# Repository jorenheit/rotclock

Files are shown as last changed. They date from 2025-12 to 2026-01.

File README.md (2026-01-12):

# Roatating Clock Device

This project rotates an entire analog wall clock so that **one selected hand remains stationary with respect to the room**.

The clock itself is a standard off-the-shelf wall clock. It is mounted inside a rigid outer ring with gear teeth. By rotating this ring at a carefully controlled speed (using a stepper motor and reduction gearing), the apparent motion of the second, minute, or hour hand can be canceled. An internal clock, based on the Arduino core function `millis()` is used to determine the frequency of the stepper motors, which is periodically synchronized with a real-time clock (DS3231) to make sure that the system keeps time correctly over longer periods of time, since `millis()` will tend to drift by multiple seconds per day on its own. 

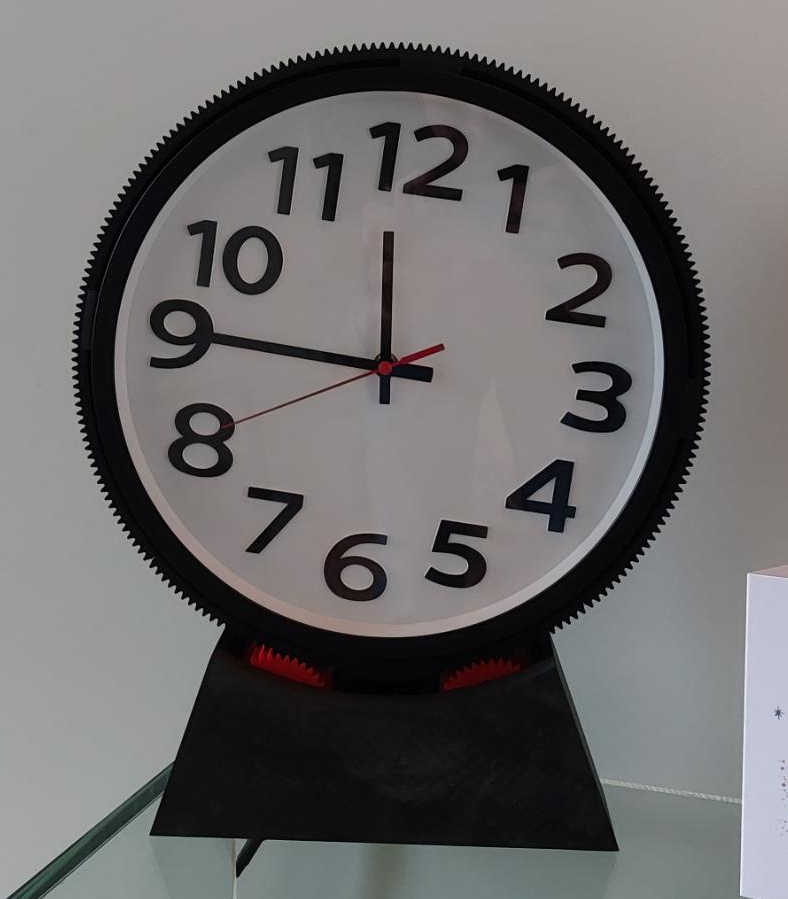
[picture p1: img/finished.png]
<p align="center"><kbd></kbd></p>

---

## How it works

- The clock is mounted in a circular frame with an external ring gear.
- A stepper motor drives this ring through a reduction gear train.
- The motor speed is chosen such that the rotation of the clock body exactly matches the angular speed of one clock hand.
- A switch selects which hand (second, minute, or hour) should appear stationary.

The clock mechanism itself is not modified.

---

## Repository contents

- **`/src`**  
  Arduino code for driving the stepper motor and handling mode selection.

- **`/3mf`**  
  3MF files for all 3D-printed mechanical parts (ring gear, mounts, brackets, etc.).

---

## Parts used

- Standard analog wall clock
- Arduino Nano (ATmega328P)
- Bipolar stepper motor
- L298-based H-bridge motor driver
- DS3231 real-time clock module
- 3D-printed parts (see `3mf` folder)
- Large ring gear (printed, 216 teeth)
- Small drive gear (printed, 36 teeth)
- 16-tooth timing pulleys (motor and driven shaft)
- Timing belt (matching pulleys)
- 3-position switch
- Miscellaneous hardware (bearings, fasteners, wiring)

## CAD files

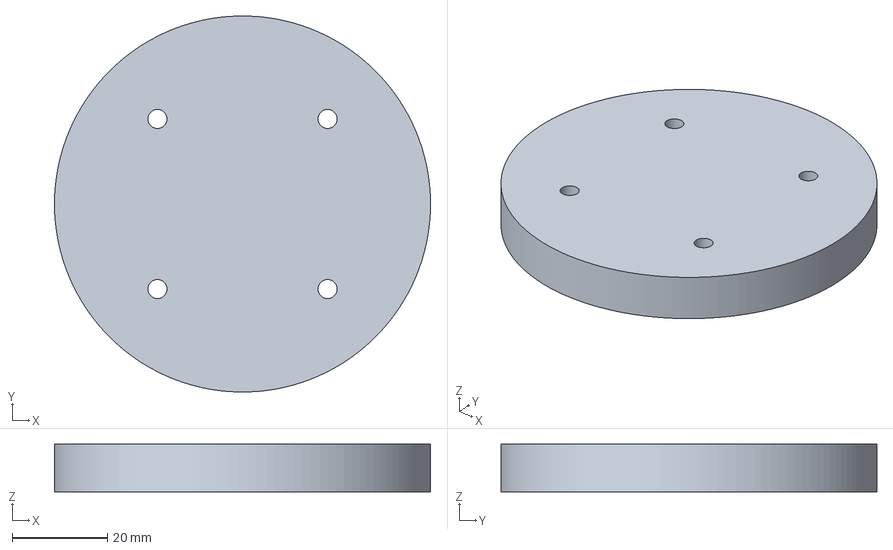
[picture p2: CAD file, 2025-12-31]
3mf/DiskCenter.3mf
79.0 x 79.0 x 10.0 mm

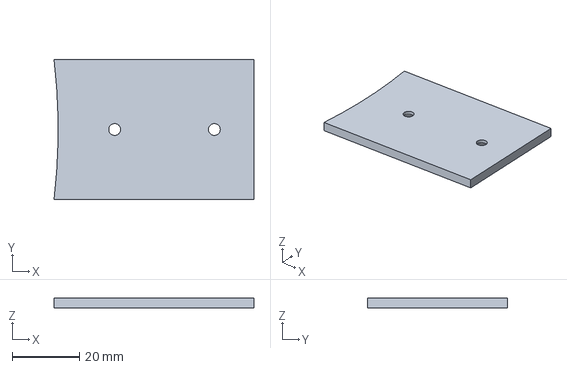
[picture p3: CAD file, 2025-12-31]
3mf/CaseLid.3mf
59.3 x 41.5 x 3.00 mm

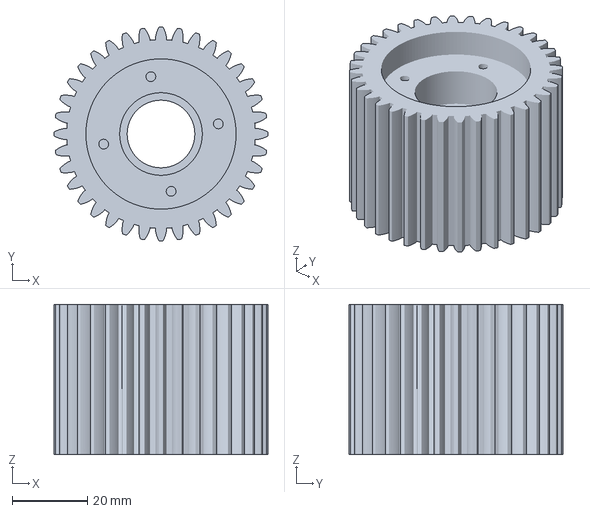
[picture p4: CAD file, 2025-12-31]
3mf/36TDriver.3mf
57.0 x 57.0 x 40.0 mm

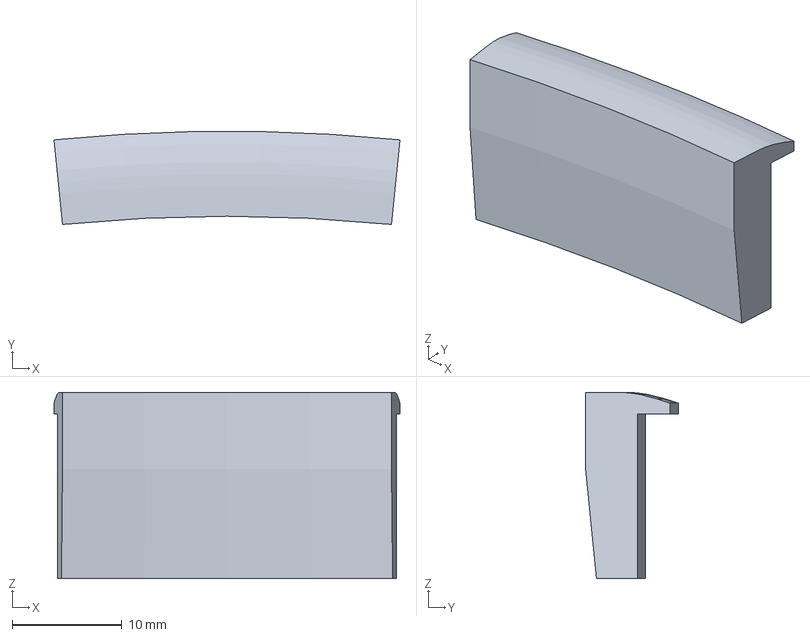
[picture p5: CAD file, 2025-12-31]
3mf/Spacer.3mf
31.5 x 8.47 x 17.0 mm

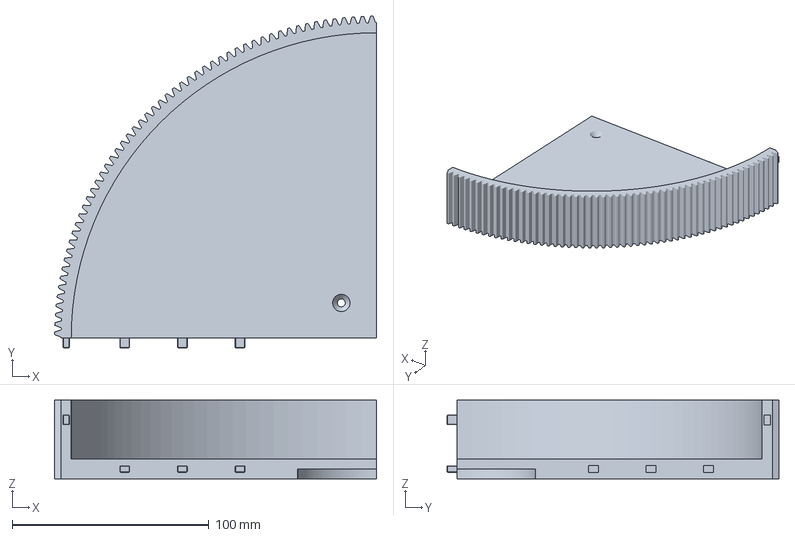
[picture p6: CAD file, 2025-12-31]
3mf/DiskQuadrant.3mf
163.5 x 168.5 x 40.0 mm

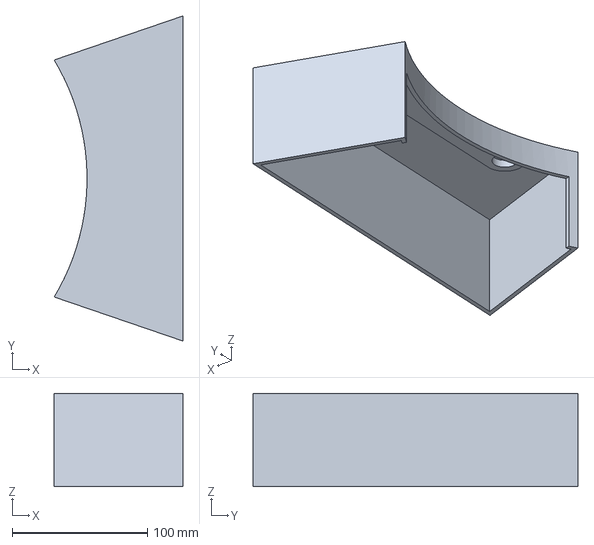
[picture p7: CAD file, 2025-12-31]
3mf/CaseFront.3mf
95.0 x 240.0 x 69.0 mm

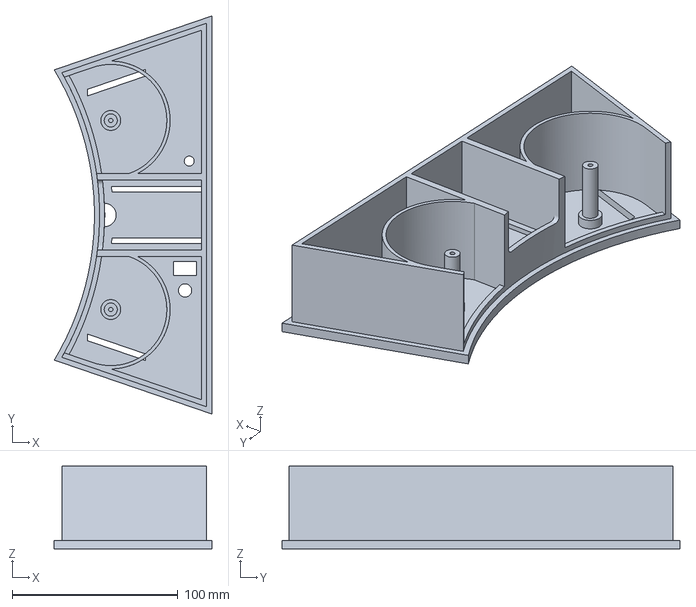
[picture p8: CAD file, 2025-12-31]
3mf/CaseBack.3mf
95.0 x 240.0 x 50.0 mm

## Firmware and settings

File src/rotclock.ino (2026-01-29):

#include "exec_every.h"
#include "rotclock.h"
#include "time.h"

enum Pins {
  CA1  = 12,
  CA2  = 11,
  CB1  = 9,   // whoops, wired in reverse
  CB2  = 10,
  SW_A = 2,
  SW_B = 3
};

enum Params {
  CLOCK_TEETH       = 216,
  GEAR_TEETH        = 36,
  MOTOR_STEPS       = 96
};

enum SyncSettings {
  SyncIntervalMillis = 100,
  NudgeOnSyncMillis = 50,
  MaxAllowedDesyncSeconds = 5
};

using RTC = time::RTC_DS3231<0x68>;
using ITC = time::ITC<NudgeOnSyncMillis, MaxAllowedDesyncSeconds>;

using Clock = ClockTurner<
  StepperMotor<CA1, CA2, CB1, CB2, MOTOR_STEPS>,
  Switch<SW_A, SW_B>,
  CLOCK_TEETH,
  GEAR_TEETH,
  ITC::millis
>;

void setup() {
  Clock::begin();
  RTC::begin();
  ITC::begin();
  ITC::set(RTC::time());
}

void loop() {
  Clock::loop();
  exec_every(SyncIntervalMillis, ITC::sync<RTC>);
}

void panic(PanicCode code) {
  while (true) Clock::wobble(code, 1000);
}

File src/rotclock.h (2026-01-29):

#pragma once
#include "util.h"
#include "time.h"

enum Direction {
  Clockwise,
  CounterClockwise
};

enum: uint32_t {
  MILLIS_PER_MINUTE   = 60UL * 1000UL,
  MILLIS_PER_HOUR     = 60UL * MILLIS_PER_MINUTE,
  MILLIS_PER_12_HOURS = 12UL * MILLIS_PER_HOUR
};

template <uint8_t SW_A, uint8_t SW_B>
class Switch {
  static constexpr uint16_t DEBOUNCE_DELAY = 50;

public:
  enum State {
    Up        = 0b01,
    Middle    = 0b11,
    Down      = 0b10,
    Undefined = 0b00
  };
  using HandlerType = void (*)(State);

private:
  Switch() = delete;
  
  static HandlerType &_handler() { static HandlerType h = nullptr; return h; }
  static State &_state() { static State s = Undefined; return s; }
  
  static bool update() { 
    State oldState = _state();
    _state() = (digitalRead<SW_B>() << 1) | digitalRead<SW_A>(); 
    return (_state() != oldState) && (_handler() != nullptr);
  }
  static void handle() { _handler()(_state()); }

public:
  static void begin(HandlerType handler) {
    pinMode(SW_A, INPUT_PULLUP);
    pinMode(SW_B, INPUT_PULLUP);
    _handler() = handler;
    update();
    handle();
  }

  static void loop() {
    exec_throttled(DEBOUNCE_DELAY, update, handle);
  }

  static State state() { return _state(); }
};

namespace StepperMotorHelper_ {
  enum Coil: uint8_t { A = 0b1100, B = 0b0011 };
  constexpr uint8_t operator+(Coil C) { return C & 0b1010; }
  constexpr uint8_t operator-(Coil C) { return C & 0b0101; }
  constexpr uint8_t operator~(Coil C) { return 0;          }

 union CoilConfig {
    uint8_t _val;
    struct { uint8_t A_1: 1; uint8_t A_2: 1; uint8_t B_1: 1; uint8_t B_2: 1; } get;
  };
}

template <uint8_t CA1, uint8_t CA2, uint8_t CB1, uint8_t CB2, uint16_t Steps>
class StepperMotor {
  StepperMotor() = delete;
 
public:
  static constexpr uint16_t STEPS_PER_REVOLUTION = Steps;

  static void begin() {
    pinMode(CA1, OUTPUT);
    pinMode(CA2, OUTPUT);
    pinMode(CB1, OUTPUT);
    pinMode(CB2, OUTPUT);
    setCoils(0);
  }

  static void halfStep(Direction dir = CounterClockwise) {
    static uint8_t index = 0;
    index = (index + (dir == Clockwise ? 1 : 7)) & 7;
    setCoils(index);
  }

private:
  static void setCoils(uint8_t index) {
    using namespace StepperMotorHelper_;
    static constexpr CoilConfig const sequence[8] = {
      +A | ~B,
      +A | +B,
      ~A | +B,
      -A | +B,
      -A | ~B,
      -A | -B,
      ~A | -B,
      +A | -B
    };

    CoilConfig const &value = sequence[index & 7];
    digitalWrite<CA1>(value.get.A_1);
    digitalWrite<CA2>(value.get.A_2);
    digitalWrite<CB1>(value.get.B_1);
    digitalWrite<CB2>(value.get.B_2);
  }
};

using Millis = uint32_t();
template <typename Motor, typename Switch, uint16_t ClockTeeth, uint16_t GearTeeth, Millis millis>
class ClockTurner {
  static_assert(ClockTeeth % GearTeeth == 0);
  static constexpr uint64_t HALFSTEPS_PER_CLOCK_REVOLUTION = 2 * (ClockTeeth / GearTeeth) * Motor::STEPS_PER_REVOLUTION;
  using SwitchState = typename Switch::State;

  ClockTurner() = delete;
  static uint32_t &_period()      { static uint32_t p = -1; return p; }
  static bool     &_initialized() { static bool i = false;  return i; }

public:
  static void begin() {
    Motor::begin();
    Switch::begin(+[](SwitchState state){      
      _initialized() = false;
      _period() = Map<
        Switch::Up,     MILLIS_PER_MINUTE, 
        Switch::Middle, MILLIS_PER_HOUR, 
        Switch::Down,   MILLIS_PER_12_HOURS
      >::at(state);
      if (_period() == -1) panic(InvalidSwitchState);
    });
  }

  static void loop() {
    static exec::Handle handle = nullptr;
    static uint64_t accumulator = 0;

    Switch::loop();
    if (!_initialized()) {
      _initialized() = true;
      exec::reset(handle);
      accumulator = 0;
    }

    auto result = exec_every_with(millis, 10, [](uint32_t dt){
        accumulator += dt * HALFSTEPS_PER_CLOCK_REVOLUTION;
        if (accumulator >= _period()) {
          accumulator -= _period();
          Motor::halfStep();
        }        
      });
    if (!handle) handle = exec::getHandle(result);
  }

  static void wobble(uint8_t const n, uint16_t const delayMillis) {
    for (uint8_t i = 0; i != n; ++i) { Motor::halfStep(Clockwise);        delay(delayMillis); }
    for (uint8_t i = 0; i != n; ++i) { Motor::halfStep(CounterClockwise); delay(delayMillis); }
  }
};

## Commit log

2025-12-31 arduino sources uploaded
2026-01-11 Synchronization with real time clock
    millis() tends to drift over time, so a real-time clock (DS3231) was added and is used to synchronize the internal clock.
    [rotclock.h, rotclock.ino]
2026-01-11 Error codes for panic
    [rotclock.h, rotclock.ino]
